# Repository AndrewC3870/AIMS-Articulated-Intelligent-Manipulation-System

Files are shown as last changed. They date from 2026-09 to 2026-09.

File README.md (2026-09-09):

# AIMS: Articulated Intelligent Manipulation System
> **A low-cost, six-degree-of-freedom (6-DoF) robotic manipulator with fully integrated Cartesian control.**

<p align="center">
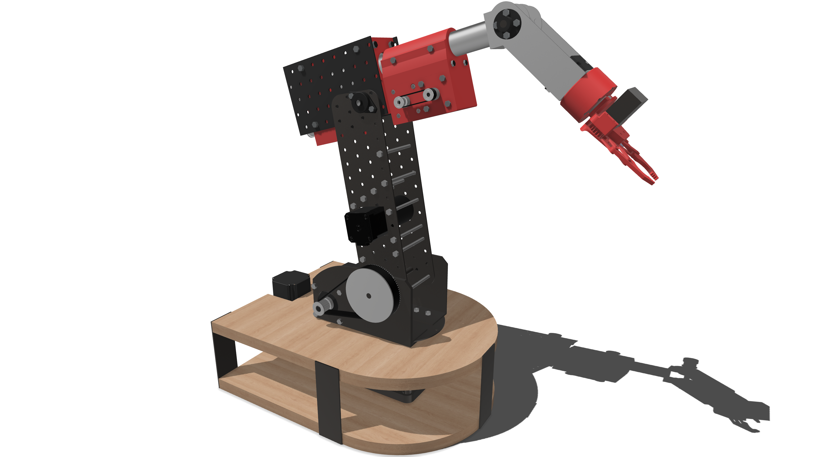
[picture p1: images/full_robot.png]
  
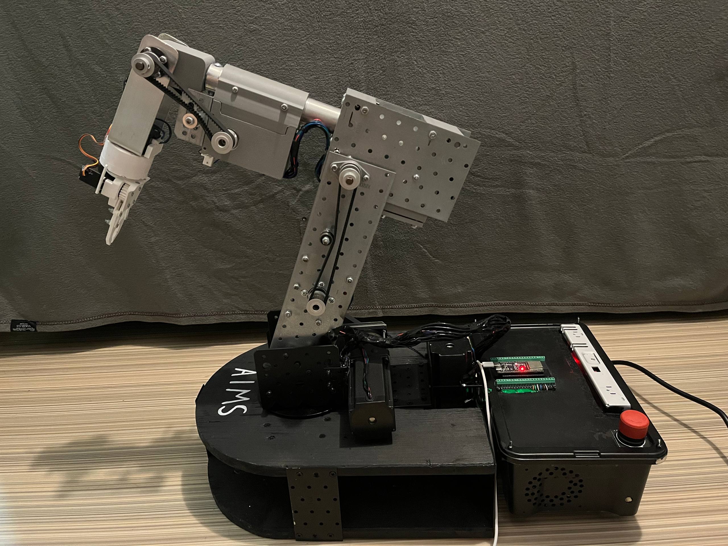
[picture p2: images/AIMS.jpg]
  
</p>

---

## Key Features

*   **Standalone Operation:** The system runs entirely on an **ESP32-S3** microcontroller. It handles inverse kinematics, motion planning, calibration, and teach-and-repeat functionality without requiring an external computer.
*   **Wireless Web Interface:** Enables intuitive, wireless control of the robot directly from any web browser.
*   **Computer Vision Integration:** A separate vision module powered by OpenCV and YOLO performs real-time object detection and workspace mapping.
*   **High Resolution, Low Cost:** Built using stepper motors, belt transmissions, and planetary gear reductions to maximize precision while keeping hardware costs down.
*   **Advanced Kinematics:** Utilizes a real-angle joint model to simplify kinematics, paired with gravity-induced deformation compensation to significantly improve accuracy under load.

## Performance & Capabilities

*   **Repeatability:** Sub-millimeter accuracy.
*   **Workspace Range:** Approximately 750 mm.
*   **Applications:** Highly efficient vision-guided manipulation and automated tasks.

##  Bill of Materials (BOM)

| Component | Qty | Usage | Source / Link |
| :--- | :---: | :--- | :---: |
| Nema 23 Stepper Motor (2.5 Nm) | 1 | Joint 1 | [Link](https://www.aliexpress.com/item/1005008345392251.html?spm=a2g0o.order_list.order_list_main.87.96b218026ZKrhr) |
| Nema 23 Stepper Motor (3.0 Nm) | 1 | Joint 2 | [Link](https://www.aliexpress.com/item/1005008357901354.html?spm=a2g0o.order_list.order_list_main.92.96b218026ZKrhr) |
| Planetary Gearbox 1:10 (Nema 23) | 1 | Joint 1 | [Link](https://www.aliexpress.com/item/1005008463841789.html?spm=a2g0o.order_list.order_list_main.78.96b218026ZKrhr) |
| Nema 17 Stepper Motor (0.7 Nm) | 2 | Joint 3 | [Link](https://www.aliexpress.com/item/1005010354201440.html?spm=a2g0o.order_list.order_list_main.77.96b218026ZKrhr) |
| Planetary Gearbox 1:20 (Nema 17) | 2 | Joint 3, Joint 5 | [Link](https://www.aliexpress.com/item/1005010354201440.html?spm=a2g0o.order_list.order_list_main.77.96b218026ZKrhr) |
| Nema 17 Stepper Motor (0.45 Nm) | 1 | Joint 5 | [Link](https://www.aliexpress.com/item/1005007293709095.html?spm=a2g0o.order_list.order_list_main.10.96b218026ZKrhr) |
| Nema 17 Stepper Motor Short/Pancake (0.16 Nm) | 1 | Joint 6 | [Link](https://www.aliexpress.com/item/1005006722496911.html?spm=a2g0o.order_list.order_list_main.112.96b218026ZKrhr) |
| Planetary Gearbox (Nema 17) | 1 | Joint 6 | [3D Printed](https://github.com/AndrewC3870/AIMS-Articulated-Intelligent-Manipulation-System/blob/e1582351b9eff7f9d4ed971e265c47a4c45c2014/step-files/PlanetaryGearbox.step) |
| 36V 400W Power Supply | 1 | Robot Power Supply | [Link](https://www.aliexpress.com/item/1005008204035607.html?spm=a2g0o.order_list.order_list_main.88.96b218026ZKrhr) |
| LM2596 DC-DC Step-Down Converter | 1 | ESP + Logic Shifters Power Supply | [Link](https://www.aliexpress.com/item/1005009448899169.html?spm=a2g0o.order_list.order_list_main.102.96b218026ZKrhr) |
| TXS0108E 3.3V to 5V Logic Level Shifter | 2 | ESP to Driver | [Link](https://www.optimusdigital.ro/ro/interfata-convertoare-de-niveluri/1380-convertor-de-niveluri-logice-bidirecional-pe-8-bii-txs0108e.html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) |
| DM556 Stepper Driver | 2 | Driver Nema 23 | [Link](https://www.aliexpress.com/item/1005008804993379.html?spm=a2g0o.order_list.order_list_main.123.96b218026ZKrhr) |
| DM542 Stepper Driver | 4 | Driver Nema 17 | [Link](https://www.aliexpress.com/item/1005007342364459.html?spm=a2g0o.order_list.order_list_main.117.96b218026ZKrhr) |
| ESP32-S3 WROOM | 1 | Brain | [Link](https://www.aliexpress.com/item/1005008957932920.html?spm=a2g0o.order_list.order_list_main.107.96b218026ZKrhr) |
| ESP32-S3 Development Board | 1 | For easy wiring | [Link](https://www.aliexpress.com/item/1005008957932920.html?spm=a2g0o.order_list.order_list_main.107.96b218026ZKrhr) |
| HTD 3M Timing Pulley (20 Teeth) | 5 | Torque transmission M3-J3, M5-J5 | [Link](https://www.aliexpress.com/item/1005008441306459.html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) |
| HTD 3M Timing Pulley (15 Teeth) | 2 | Torque transmission M4-J4 | [Link](https://www.aliexpress.com/item/1005008441306459.html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) |
| HTD 3M Timing Pulley (80 Teeth) | 1 | Torque transmission M2-J2 | [Link](https://www.aliexpress.com/item/1005007835192076.html?spm=a2g0o.order_list.order_list_main.15.96b218026ZKrhr) |
| HTD 3M Timing Pulley (150 Teeth) | 1 | Torque transmission M1-J1 | [3D Printed](https://github.com/AndrewC3870/AIMS-Articulated-Intelligent-Manipulation-System/blob/e1582351b9eff7f9d4ed971e265c47a4c45c2014/step-files/Pulley.step) |
| HTD 3M Timing Belts (276, 357, 390, 681) | 4 | Torque transmission (1 of each) | [Link](https://www.aliexpress.com/item/1005008698694885.html?spm=a2g0o.order_list.order_list_main.25.96b218026ZKrhr) |
| GT2 Pulley (20 Teeth) | 2 | Motor to gearbox torque transmission J5 | [Link](https://www.aliexpress.com/item/1005008698694885.html?spm=a2g0o.order_list.order_list_main.25.96b218026ZKrhr) |
| GT2 Belt (124mm) | 1 | Motor to gearbox torque transmission J5 | [Link](https://www.aliexpress.com/item/1005008878754443.html?spm=a2g0o.order_list.order_list_main.40.96b218026ZKrhr) |
| Micro Limit Switch (SPDT) | 6 | Homing | [Link](https://www.aliexpress.com/item/1005008226608212.html?spm=a2g0o.order_list.order_list_main.20.96b218026ZKrhr) |
| KLF 08 Shaft Support / Coupler | 6 | Assembly | [Link](https://www.aliexpress.com/item/1005005167837896.html?spm=a2g0o.order_list.order_list_main.61.96b218026ZKrhr) |
| Flange | 6 | Assembly | [Link](https://www.aliexpress.com/item/1005009915654076.html?spm=a2g0o.order_list.order_list_main.51.96b218026ZKrhr) |
| Emergency Stop Button | 1 | Emergency stop | [Link](https://www.dedeman.ro/ro/buton-ciuperca-cu-retinere-freder-d40-32-765-contact-normal-inchis-ip40/p/1032603) |
| Aluminum Pipe (30x2x300mm) | 1 | Joint 4 Structure | [Link](https://www.emag.ro/teava-aluminiu-rotunda-30x2mm-lungime-40cm-gal-industrial-rurok-stnd-al-30x2-x40/pd/DPVCXRYBM/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) |
| CAT5e Wire | 1 | Wiring for data | [Link](https://www.bricodepot.ro/cablu-retea-utp-cat5e-omnicable-alb-metru/cpd/100866006/) |
| 2.5mm² Wire | 1 | Wiring for power | [Link](https://www.bricodepot.ro/cablu-electric-omnicable-myym-4-x-2-5mm2-alb-metru/cpd/100866026/) |
| Bolts and Nuts | A lot | Assembly | Brico |

Now I'm working on an Assembly manual, will be added soon!

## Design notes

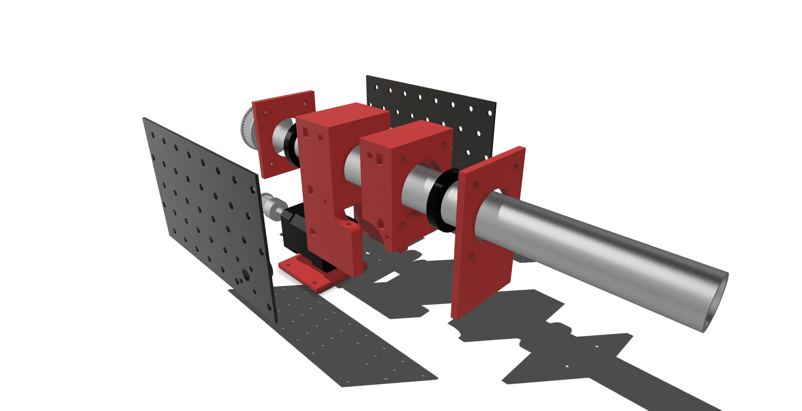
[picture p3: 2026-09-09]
images/J3_Exxploded_view.png

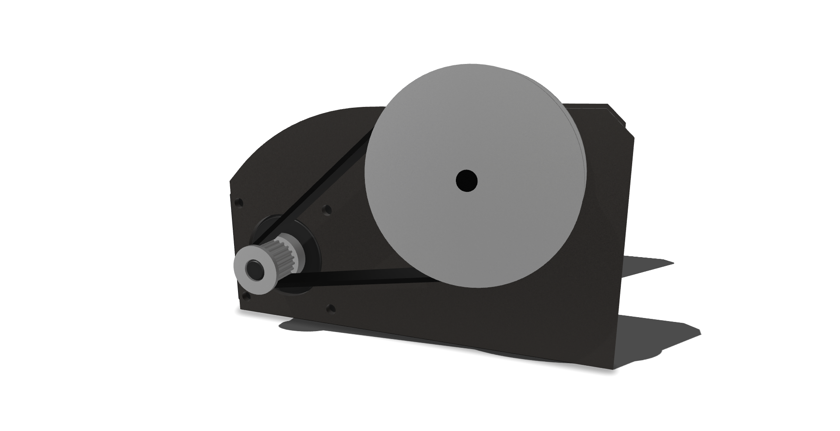
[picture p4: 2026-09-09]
images/j2-3.png

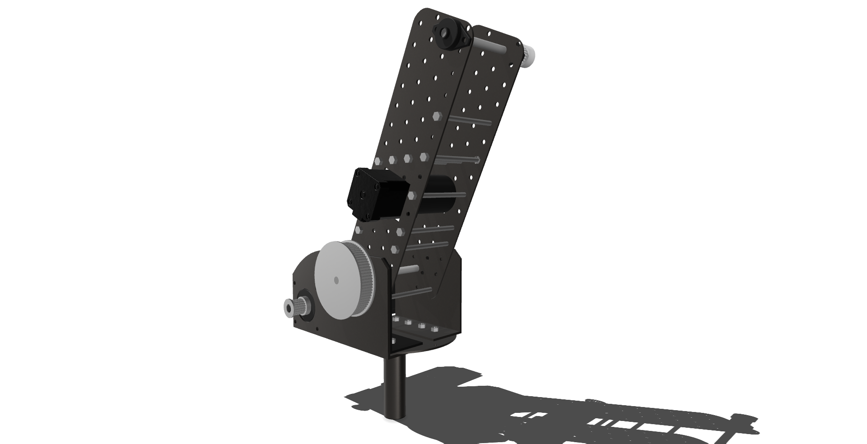
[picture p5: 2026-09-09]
images/J2.png

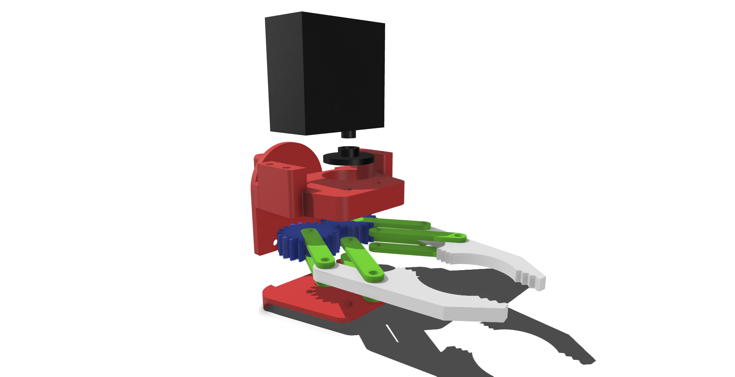
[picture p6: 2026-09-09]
images/Gripper_Exploded.png

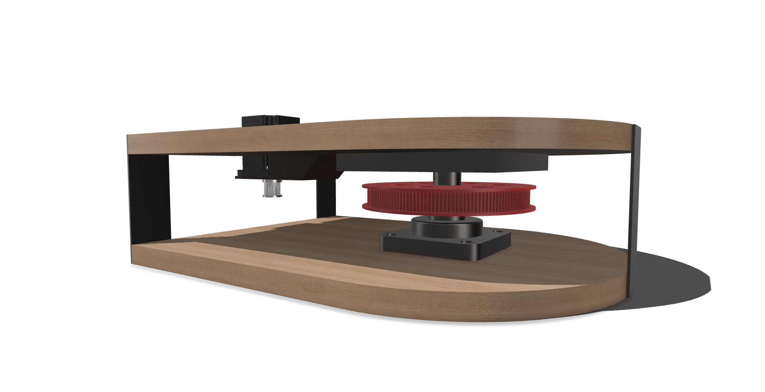
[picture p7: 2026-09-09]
images/Base3.png

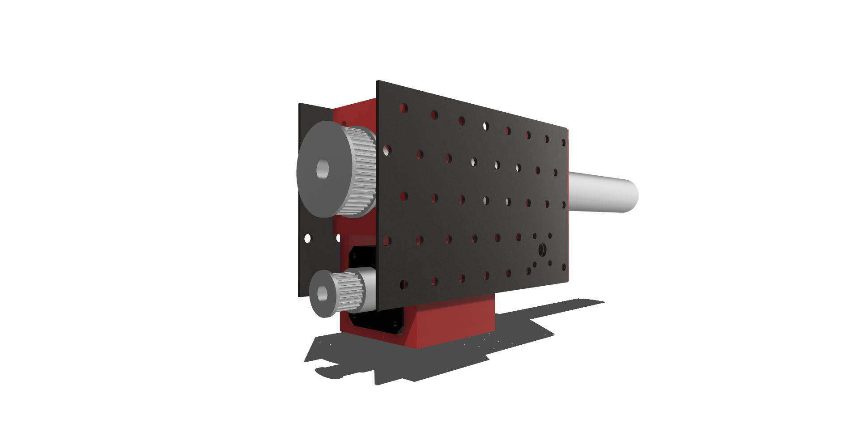
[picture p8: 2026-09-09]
images/J3_Asembled.png

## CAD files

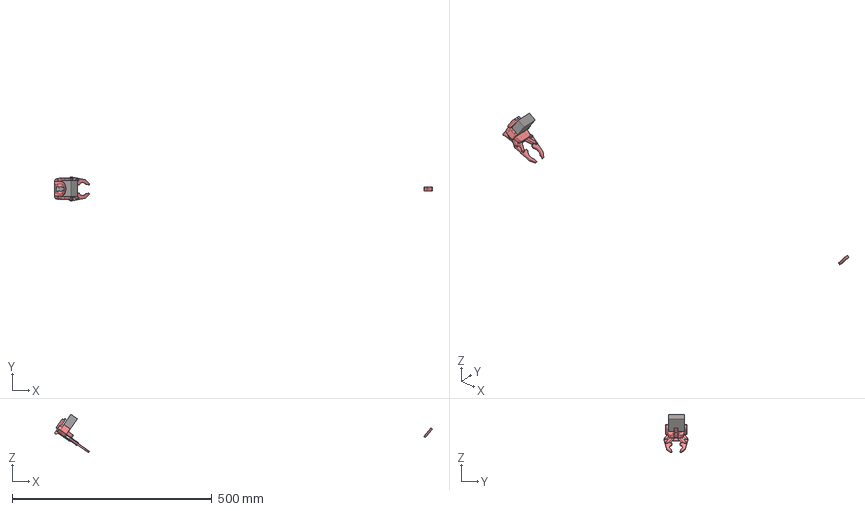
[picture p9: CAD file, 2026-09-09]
step-files/Gripper.step
946.4 x 60.0 x 96.3 mm
Ring_Gear_Output.step
gear x 2

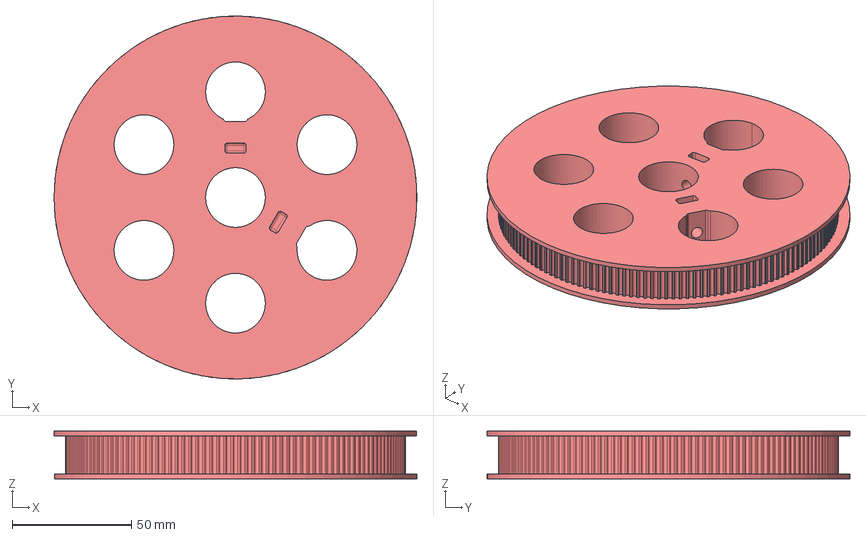
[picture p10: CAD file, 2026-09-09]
step-files/Pulley.step
152.0 x 151.9 x 20.0 mm

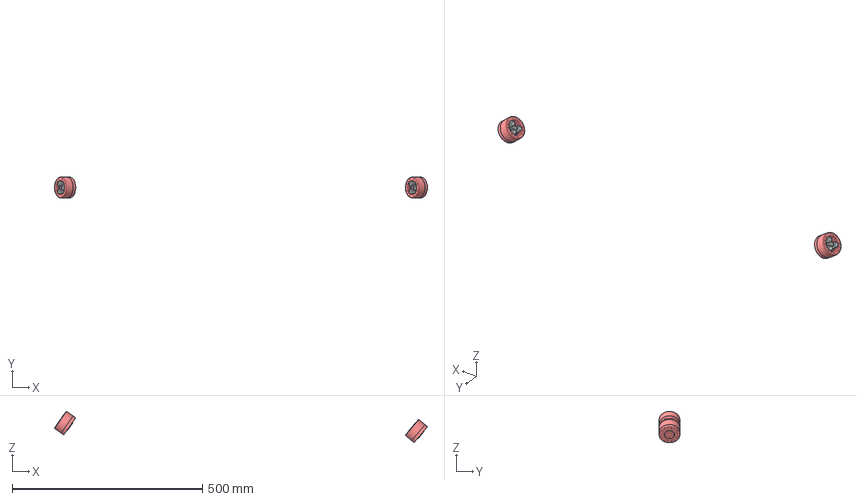
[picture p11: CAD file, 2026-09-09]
step-files/PlanetaryGearbox.step
980.1 x 55.0 x 82.3 mm
Outer_Shell.step
Planet_Carrier.step
Planet_Gear.step
Ring_Gear_Output.step
Sun_Gear.step

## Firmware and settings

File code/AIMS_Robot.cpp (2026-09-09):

// ==============================================================================
//  File map:
//    Config.h         pins, gear ratios, offsets, limits, Wi-Fi, shared types
//    Globals.h/.cpp   all shared mutable state (steppers, servo, path, flags...)
//    WebPage.h        the dashboard HTML
//    WebInterface     Wi-Fi AP, HTTP route, WebSocket parsing
//    Homing           limit-switch homing + post-home offsets
//    Training         waypoint recording
//    Motion           main-loop helpers (flags, playback, stepper run)
//    AIMS_Robot.cpp   this file - setup() and loop() only
// ==============================================================================

#include <Arduino.h>

#include "Config.h"
#include "Globals.h"
#include "Homing.h"
#include "WebInterface.h"
#include "Motion.h"

void setup() {
  Serial.begin(115200);
  Serial.println("\n[System] Booting up AIMS Robot Controller...");

  pinMode(SW1_PIN, INPUT_PULLUP);
  pinMode(SW2_PIN, INPUT_PULLUP);
  pinMode(SW3_PIN, INPUT_PULLUP);
  pinMode(SW4_PIN, INPUT_PULLUP);
  pinMode(SW5_PIN, INPUT_PULLUP);
  pinMode(SW6_PIN, INPUT_PULLUP);

  gripperServo.setPeriodHertz(50);
  gripperServo.attach(GRIPPER_PIN, 500, 2500);

  for (int i = 0; i < 6; i++) {
    steppers[i]->setMaxSpeed(6000);
    steppers[i]->setAcceleration(1200);
    steppers[i]->setMinPulseWidth(20);
  }


  stepperJ1.setPinsInverted(true, false, false);
  stepperJ3.setPinsInverted(true, false, false);
  stepperJ4.setPinsInverted(true, false, false);

  // Register all axes with the coordinated mover used for smooth line/draw motion.
  for (int i = 0; i < 6; i++) {
    multiDraw.addStepper(*steppers[i]);
  }

  loadCalibration();   // restore gripper angles + training profiles from flash

  Serial.println("Starting Wi-Fi Access Point...");
  setupWebServer();   // WiFi.softAP + routes + websocket + server.begin()

  Serial.println("Web Server Started Successfully!");

  delay(1000);
  executeHardwareHome();
}


void loop() {
  ws.cleanupClients();

  processCommandFlags();   // HOME / RESET / STOP_TRAIN / PLAY / PAUSE + sliders
  updatePlayback();        // PLAYING state machine
  runAllSteppers();        // step every motor once
}

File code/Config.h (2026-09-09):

#pragma once
#include <Arduino.h>

// Stepper pins
#define J1_STEP 4
#define J1_DIR  5
#define J2_STEP 6
#define J2_DIR  7
#define J3_STEP 15
#define J3_DIR  16
#define J4_STEP 17
#define J4_DIR  18
#define J5_STEP 8
#define J5_DIR  3
#define J6_STEP 46
#define J6_DIR  9

// Limit switches
#define SW6_PIN 1
#define SW3_PIN 2
#define SW5_PIN 42
#define SW4_PIN 41
#define SW2_PIN 40
#define SW1_PIN 39

// Gripper servo
#define GRIPPER_PIN 12

const float STEPS_DEG[] = {
  (3200.0 * 10.0) / 360.0,
  (3200.0 * 40.0) / 360.0,
  (3200.0 * 20.0) / 360.0,
  (3200.0 * 3.0)  / 360.0,
  (3200.0 * 20.0) / 360.0,
  (3200.0 * 4.0)  / 360.0
};

// Home offsets
const float SAFE_HOME_ANGLES[6] = {86.0, 0.0, 0.0, -146.0, -40.0, 155.0};


// Path memory
const int MAX_WAYPOINTS = 100;
const int SERVO_WAIT_TIME = 500;
const int NUM_PROFILES = 4;
const float DRAW_SPEED = 2000.0;
const int   DRAW_RAMP_SEGS = 8;
const float DRAW_MIN_FACTOR = 0.25;

// Wi-Fi AP
const char* const WIFI_SSID = "AIMS_ROBOT";
const char* const WIFI_PASSWORD = "password123";

// Kinematics
const float KIN_L1         = 199.0;
const float KIN_L2         = 250.4;
const float KIN_D_SHOULDER = 11.0;
const float KIN_L3         = 251.6;
const float KIN_D_ELBOW    = 41.0;
const float KIN_L4         = 251.0;
const float KIN_D_TIP      = 17.0;

//  SAG / DROOP COMPENSATION
const bool  COMP_ENABLE = true;
const float COMP_Z_SLOPE  = 0.23f;
const float COMP_Z_R0 = 324.0f;
const float COMP_R_OFFSET = 13.0f;
const float COMP_R_SLOPE = 0.0f;
const float COMP_R_R0 = 300.0f;
const float COMP_MAX_MM = 35.0f;


const float DIR_SIGN[6]       = {  1.0, -1.0,  -1.0,    1.0,   1.0,    1.0 };
const float HOME_ANGLE_DEG[6] = {  0.0,-53.0, 102.7,    0.0,  76.0,    0.0 };


const float TRAVEL_MIN_DEG[6] = { -90.0,   0.0, -81.0, -140.0, -110.0, -180.0 };
const float TRAVEL_MAX_DEG[6] = {  90.0, 100.0,   0.0,  180.0,   40.0,  150.0 };

inline float jointMin(int i) { return HOME_ANGLE_DEG[i] + TRAVEL_MIN_DEG[i]; }
inline float jointMax(int i) { return HOME_ANGLE_DEG[i] + TRAVEL_MAX_DEG[i]; }


//  SHARED TYPES
enum RobotState { IDLE, HOMING, TRAINING, PLAYING, PAUSED };

struct Waypoint {
  long positions[6];
  int  gripperAngle;
};

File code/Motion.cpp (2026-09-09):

#include "Motion.h"
#include <Arduino.h>
#include "Config.h"
#include "Globals.h"
#include "Homing.h"
#include "WebInterface.h" 

// Playback Timers (local to the playback state machine)
static unsigned long waypointPauseTime = 0;
static bool isPausing = false;
static void restoreNormalSpeed();
static void resyncSteppers();
static void setDrawRampSpeed(int segIdx);
static void writeGripper(int angle);

//  COMMAND FLAGS 
void processCommandFlags() {
  // EMERGENCY STOP: handled first, halts everything immediately
  if (flagTriggerEstop) {
    flagTriggerEstop = false;
    currentState = IDLE;
    playOnce = false;
    recording = false;
    resyncSteppers();
    restoreNormalSpeed();
    for (int i = 0; i < 6; i++) 
      flagUpdateSteppers[i] = false;

    Serial.println("EMERGENCY STOP");
    ws.textAll("ESTOPPED");
    broadcastSync();
    return;
  }

  // drive every joint back to the home pose
  if (flagTriggerDefault) {
    flagTriggerDefault = false;
    currentState = IDLE;
    playOnce = false;
    resyncSteppers();
    restoreNormalSpeed();
    Serial.println("Returning to home pose.");
    for (int i = 0; i < 6; i++) {
      long hs = (long)(DIR_SIGN[i] * HOME_ANGLE_DEG[i] * STEPS_DEG[i]);
      uiTargetSteps[i] = hs;
      steppers[i]->moveTo(hs);
    }
    writeGripper(gripOpenAngle);
    broadcastSync();
  }

  if (flagTriggerHome) {
    flagTriggerHome = false;
    executeHardwareHome();
  }

  // Reset logic
  if (flagTriggerReset) {
    flagTriggerReset = false;
    pathLength = 0;
    playbackIndex = 0;
    ws.textAll("POINTS:0");

    Serial.println("Reset and drive home");
    currentState = IDLE;

    for (int i = 0; i < 6; i++) {
      long hs = (long)(DIR_SIGN[i] * HOME_ANGLE_DEG[i] * STEPS_DEG[i]);
      uiTargetSteps[i] = hs;
      steppers[i]->moveTo(hs);
    }
    writeGripper(gripOpenAngle);
  }

  if (flagTriggerStopTrain) {
    flagTriggerStopTrain = false;
    Serial.println("Training stopped, returning to Start Point.");
    currentState = IDLE;
    for (int i = 0; i < 6; i++) {
      uiTargetSteps[i] = path[0].positions[i];
      steppers[i]->moveTo(path[0].positions[i]);
    }
    writeGripper(path[0].gripperAngle);
  }

  if (flagTriggerPlay) {
    flagTriggerPlay = false;
    if (pathLength > 0) {
      currentState = PLAYING;
      if (playOnce) {
        Serial.println("DRAW");
        setDrawRampSpeed(playbackIndex);
        long pos[6];

        for (int i = 0; i < 6; i++) 
          pos[i] = path[playbackIndex].positions[i];

        multiDraw.moveTo(pos);
        writeGripper(path[playbackIndex].gripperAngle);
      } else {
        Serial.println("PLAYING");

        for (int i = 0; i < 6; i++) 
          steppers[i]->moveTo(path[playbackIndex].positions[i]);
        writeGripper(path[playbackIndex].gripperAngle);
      }
    }
  }

  if (flagTriggerPause) {
    flagTriggerPause = false;
    Serial.println("PAUSED");
    currentState = PAUSED;
    playOnce = false;
    resyncSteppers();
    restoreNormalSpeed();
  }

  // Slider Movements
  for (int i = 0; i < 6; i++) {
    if (flagUpdateSteppers[i]) {
      flagUpdateSteppers[i] = false;
      steppers[i]->moveTo(uiTargetSteps[i]);
    }
  }
}


static void restoreNormalSpeed() {
  for (int i = 0; i < 6; i++) {
    steppers[i]->setMaxSpeed(6000);
    steppers[i]->setAcceleration(1200);
  }
}

static void resyncSteppers() {
  for (int i = 0; i < 6; i++) {
    long p = steppers[i]->currentPosition();
    steppers[i]->setCurrentPosition(p); // resets internal speed state, target = p
    steppers[i]->moveTo(p);
    uiTargetSteps[i] = p;
  }
}


static void setDrawRampSpeed(int segIdx) {
  float up = (float)(segIdx + 1) / DRAW_RAMP_SEGS;
  float down = (float)(pathLength - segIdx) / DRAW_RAMP_SEGS;
  float f = up;
  if (down < f)
    f = down;
  if (f > 1.0f)
    f = 1.0f;
  if (f < DRAW_MIN_FACTOR)
    f = DRAW_MIN_FACTOR;
  for (int i = 0; i < 6; i++)
    steppers[i]->setMaxSpeed(DRAW_SPEED * f);
}


static void writeGripper(int angle) {
  if (angle < 0)
    angle = 0;
  if (angle > 180)
    angle = 180;
  gripperAngleCmd = angle;
  gripperServo.write(angle);
}

static void updateDraw() {
  if (!multiDraw.run()) {
    playbackIndex++;
    if (playbackIndex >= pathLength) {
      playOnce = false;
      currentState = IDLE;
      resyncSteppers();
      restoreNormalSpeed();
      Serial.println("Draw complete.");
      broadcastSync();
      return;
    }
    setDrawRampSpeed(playbackIndex);
    long pos[6];
    for (int i = 0; i < 6; i++)
      pos[i] = path[playbackIndex].positions[i];
    multiDraw.moveTo(pos);
    writeGripper(path[playbackIndex].gripperAngle);
  }
}

void updatePlayback() {
  if (currentState != PLAYING) return;

  if (playOnce) { 
    updateDraw();
    return;
  }

  bool allReached = true;
  for (int i = 0; i < 6; i++) {
    if (steppers[i]->distanceToGo() != 0) { allReached = false; break; }
  }
  if (allReached) {
    if (!isPausing) { 
     isPausing = true; 
      waypointPauseTime = millis();
    }

    if (millis() - waypointPauseTime >= (unsigned long)SERVO_WAIT_TIME) {
      playbackIndex++;
      if (playbackIndex >= pathLength) {
        playbackIndex = 0;
        Serial.println(" Loop complete. Restarting from Waypoint 0.");
      }
      for (int i = 0; i < 6; i++) 
        steppers[i]->moveTo(path[playbackIndex].positions[i]);

      writeGripper(path[playbackIndex].gripperAngle);
      isPausing = false;
    }
  } else {
    isPausing = false;
  }
}

void runAllSteppers() {
  if (currentState == PLAYING && playOnce)
    return;
  for (int i = 0; i < 6; i++) {
    steppers[i]->run();
  }
}

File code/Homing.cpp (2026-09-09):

#include "Homing.h"
#include <Arduino.h>
#include "Config.h"
#include "Globals.h"

// ==============================================================================
//  HARDWARE HOMING & OFFSETS
// ==============================================================================
void homeJoint(AccelStepper* stepper, int limitPin, int direction) {
  pinMode(limitPin, INPUT_PULLUP);

  stepper->setMaxSpeed(1000);
  stepper->setAcceleration(10000);
  stepper->move(1000000 * direction);

  while (digitalRead(limitPin) == LOW) {
    stepper->run();
    yield();
  }

  stepper->stop();
  while (stepper->distanceToGo() != 0) {
    stepper->run();
    yield();
  }

  stepper->setAcceleration(1000);

  stepper->move(-1200 * direction);
  while (stepper->distanceToGo() != 0) {
    stepper->run();
    yield();
  }

  stepper->setCurrentPosition(0);

  stepper->setMaxSpeed(6000);
  stepper->setAcceleration(1200);
}

void moveOffsetAfterHoming(AccelStepper* stepper, int jointIndex, float angleOffset) {
  if (angleOffset != 0.0) {
    Serial.printf("Applying offset: Moving J%d by %.2f degrees...\n", jointIndex + 1, angleOffset);

    long targetStep = (long)(angleOffset * STEPS_DEG[jointIndex]);
    stepper->moveTo(targetStep);

    while (stepper->distanceToGo() != 0) {
      stepper->run();
      yield();
    }
  }

  long homeSteps = (long)(DIR_SIGN[jointIndex] * HOME_ANGLE_DEG[jointIndex] * STEPS_DEG[jointIndex]);
  stepper->setCurrentPosition(homeSteps);
  uiTargetSteps[jointIndex] = homeSteps;
}

void executeHardwareHome() {
  currentState = HOMING;
  Serial.println("Starting Homing Sequence");

  // Notice we pull the offsets directly from the SAFE_HOME_ANGLES array now!
  Serial.println("Homing J1...");
  homeJoint(&stepperJ1, SW1_PIN, -1);
  moveOffsetAfterHoming(&stepperJ1, 0, SAFE_HOME_ANGLES[0]);

  Serial.println("Homing J2...");
  homeJoint(&stepperJ2, SW2_PIN, 1);
  moveOffsetAfterHoming(&stepperJ2, 1, SAFE_HOME_ANGLES[1]);

  Serial.println("Homing J3...");
  homeJoint(&stepperJ3, SW3_PIN, -1);
  moveOffsetAfterHoming(&stepperJ3, 2, SAFE_HOME_ANGLES[2]);

  Serial.println("Homing J4...");
  homeJoint(&stepperJ4, SW4_PIN, 1);
  moveOffsetAfterHoming(&stepperJ4, 3, SAFE_HOME_ANGLES[3]);

  Serial.println("Homing J5...");
  homeJoint(&stepperJ5, SW5_PIN, 1);
  moveOffsetAfterHoming(&stepperJ5, 4, SAFE_HOME_ANGLES[4]);

  Serial.println("Homing J6...");
  homeJoint(&stepperJ6, SW6_PIN, -1);
  moveOffsetAfterHoming(&stepperJ6, 5, SAFE_HOME_ANGLES[5]);

  Serial.println("Limit switches found, all Ready!");

  // Update the UI via WebSockets after Homing completes
  String syncData = "SYNC:" + String(gripOpenAngle) + ":" + String(gripCloseAngle) + ":" + String(gripperServo.read());
  for (int i = 0; i < 6; i++) {
    float deg = (float)uiTargetSteps[i] / STEPS_DEG[i] * DIR_SIGN[i]; // real angle
    syncData += ":" + String(deg, 2);
  }
  ws.textAll(syncData);

  currentState = IDLE;
}

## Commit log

2026-09-09 images, sch, folders
    [AIMS.kicad_sch]
2026-09-09 Update links for 3D printed components in README
2026-09-09 Update README with assembly manual notice
    Added note about upcoming assembly manual.
